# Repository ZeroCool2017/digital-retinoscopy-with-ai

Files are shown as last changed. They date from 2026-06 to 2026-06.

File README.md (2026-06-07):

# Digital Retinoscopy with AI

A self-contained digital retinoscope head that replaces the rubber eyecup on any standard retinoscope. Real-time reflex visualization on a round display. Under $50 in parts.

**Built by an optometrist, for the 1 billion people without access to basic eye exams.**

## What it is

- ESP32-S3 XIAO Sense camera → 240x240 round GC9A01 display
- Real-time retinoscopy reflex — no phone, no laptop, no cloud
- 3D printed housing replaces the rubber eyecup
- 20D 55mm lens for magnification with adjustable sliding focus
- Battery-powered (JST 1.25mm LiPo, 500-1000mAh)
- Total BOM cost: ~$34-50

## Repository contents

```
firmware/
  standalone_demo.ino    — working OV2640 firmware (RGB565, ~15fps)

hardware/
  stl/                   — 2 STL files for printing
    ret-adapter-main-body.stl
    ret-adapter-lens-carriage.stl
  ret-adapter.scad       — parametric OpenSCAD design
  generate_stl.py        — Python script to regenerate STLs

docs/
  eyemote-pitch.md       — general pitch / grant proposal
  eyemote-pitch-lanier.md — pitch for Jaron Lanier / Microsoft Research
  CITATIONS.md           — references and sources
```

## Print settings

| Part | Material | Layer | Supports | Infill |
|---|---|---|---|---|
| Main body | PETG | 0.15-0.2mm | None | 25% |
| Lens carriage | PETG | 0.15mm | None | 25% |

## Assembly

1. Press 20D 55mm lens into lens carriage
2. Insert OV2640 camera module into body pocket, route FPC ribbon through slot
3. Slide lens carriage into front of body — twist to focus
4. Mount XIAO + LiPo battery on the flat back pocket
5. Round display mounts on the back facing you
6. Slide peephole socket over retinoscope tube (replaces rubber eyecup)
7. Twist lens carriage until reflex is sharp on screen

## BOM

| Part | Cost |
|---|---|
| XIAO ESP32S3 Sense | ~$12 |
| GC9A01 round display | ~$8 |
| 20D 55mm lens | ~$6 |
| LiPo battery 500mAh JST1.25 | ~$6 |
| 3D printed parts | ~$2 |
| Misc (ribbon, wire) | ~$2 |
| **Total** | **~$34-50** |

## Next: AI pipeline

Current prototype is standalone camera→display. Next step:
- Raspberry Pi data capture for reflex video recording
- Upload pipeline for AI-based retinopathy screening
- Telemedicine — remote preceptor sees what student sees

## License

Open source — hardware design and firmware.

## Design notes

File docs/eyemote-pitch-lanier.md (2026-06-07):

# Eyemote — Pitch for Jaron Lanier / Microsoft Research

**Subject: A $50 digital retinoscope — hardware is built, need the data pipeline**

---

Jaron,

I'm an optometrist in Oklahoma (Caddo Nation) and a self-taught hardware engineer. I built a digital retinoscope head that replaces the rubber eyecup on any standard retinoscope for $50 in parts.

**What it is:**
ESP32-S3 XIAO Sense camera → round 240x240 display. Real-time. No phone. No laptop. No cloud. The examiner sees the retinoscopy reflex on the display instead of through a peephole. The whole device slides onto the retinoscope the same way the rubber eyecup did.

**What it costs:**
- Parts: $34–$50
- Commercial equivalent (Keeler): $3,000
- That's not a 2x difference. That's 60x.

**Why it matters:**
1 billion people lack access to basic eye exams. Retinoscopy is how every child gets their first glasses — but it's the hardest skill to teach because the preceptor can't see what the student sees. A $50 device that shows the reflex in real-time changes who can learn this skill, where it can be practiced, and how much it costs to deliver.

Microsoft AI for Health already has AI models for diabetic retinopathy screening. Those models need high-quality input. My device can produce that input in any clinic, for $50, connected to a Raspberry Pi.

**What I need from Microsoft Research:**
- Help with the Raspberry Pi data pipeline (recording reflex video, structured data upload)
- A connection to the AI for Health team for clinical validation
- $15k–$30k for 100 field-test units in rural Oklahoma and tribal clinics

**What Microsoft gets:**
- A hardware platform that feeds real retinoscopy data into your AI pipeline
- A direct deployment path into underserved communities (I'm already in them)
- A demonstration that low-cost open-source hardware can match clinical-grade tools

I built the thing. The STLs print in 4 hours. The lens is in hand. The camera works. What I don't have is the software layer that turns a live reflex into a recorded, uploadable, AI-readable dataset.

Do you know anyone at Microsoft who'd want to close that gap with me?

— Dr. Lindsey Marvel, O.D.
  Eyemote Vision, Caddo Nation, Oklahoma

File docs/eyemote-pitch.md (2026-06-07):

# Eyemote: A $50 Digital Retinoscope for Global Eye Care

**Who I am**
Dr. Lindsey Marvel, O.D. — optometrist, Caddo Nation, Oklahoma. Self-taught hardware engineer. I've spent the last year building the hardware I wish existed when I was learning retinoscopy.

**The problem**
Retinoscopy is the single most important skill for determining a patient's prescription — especially in children, nonverbal patients, and anyone who can't sit through a subjective refraction. It's also the hardest skill to teach and learn.

Commercial digital retinoscopes (Keeler, Welch Allyn) cost $3,000–$8,000. They're video recorders bolted onto a $50 light. They don't help you *see* the reflex better — they help you *record* it. A whole generation of optometry students graduates without confidence in retinoscopy because their preceptor can't look through the scope with them.

**The solution**
A self-contained digital retinoscope head that replaces the rubber eyecup. It costs under $50 in parts:

- ESP32-S3 XIAO Sense ($12) — camera + processor + WiFi
- Round 240x240 GC9A01 display ($8)
- 20D 55mm magnifying lens ($6)
- 3D printed housing ($2)
- 500mAh LiPo battery ($6)

Total: ~$34–$50 depending on sourcing.

**How it works**
The camera captures the retinoscopy streak reflex in real-time. The round display shows it to the examiner — no phone, no laptop, no cable, no cloud. The whole device replaces the rubber eyecup on any standard retinoscope. You hold the retinoscope normally, look at the display instead of the peephole, and see the reflex in real-time — exactly the same motion you already use.

**The underserved angle**
Retinoscopy is how every child gets their first glasses prescription. In rural Oklahoma, on tribal lands, in community health centers — there are clinics where a $3,000+ digital retinoscope will never be approved. A $50 device that fits in a pocket doesn't need purchase orders. It doesn't need IT support. It needs a USB-C cable and a 3D printer.

For global eye care: the World Health Organization estimates 1 billion people lack access to basic eye exams. The equipment gap isn't technology — it's cost. A device at this price point changes who gets care and who doesn't.

**Where it goes next**
The current prototype is standalone: camera → display, real-time, no latency. The next step is adding a Raspberry Pi data pipeline for:

- Recording reflex videos for teaching
- Uploading to Microsoft AI for diabetic retinopathy screening
- Telemedicine: a remote preceptor can see exactly what the student sees
- Training AI models on real retinoscopy reflexes (nobody has this dataset)

**What I need**
- $15,000–$30,000 to refine the hardware, run clinical validation, and produce 100 units for field testing
- An engineering partner to help with the Raspberry Pi integration and data pipeline
- Clinical partners in rural and underserved settings to test and validate

**Why now**
Microsoft AI for Health has the AI. Keeler has the $3,000 device. Nobody has connected them to the 200,000 optometrists who just need a $50 tool to do their job better. The hardware is done. The lens is in hand. The STL files print in 4 hours. The only missing piece is the bridge between clinic and cloud.

---

**Contact**
Dr. Lindsey Marvel, O.D.
Eyemote Vision
Caddo Nation, Oklahoma

*"I can't see the reflex" should never be the reason a child goes without glasses.*

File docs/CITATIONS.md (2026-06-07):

# References

## Global eye care burden

1. World Health Organization. *World report on vision*. Geneva: WHO, 2019.
   - 1 billion people worldwide have a vision impairment that could have been prevented or is yet to be addressed.
   - https://www.who.int/publications/i/item/9789241516570

2. Burton MJ, et al. *The Lancet Global Health Commission on Global Eye Health: vision beyond 2020*. Lancet Glob Health. 2021;9(4):e489-e551.
   - https://doi.org/10.1016/S2214-109X(20)30488-5

3. Resnikoff S, et al. *Estimated number of ophthalmologists worldwide*. Int Ophthalmol. 2020;40(7):1579-1591.

## Retinoscopy & refraction

4. American Academy of Ophthalmology. *Basic and Clinical Science Course: Clinical Optics*. 2023-2024.
   - Standard reference for retinoscopy technique and equipment.

5. Hrynchak P, et al. *The accuracy of retinoscopy*. Optom Vis Sci. 2013;90(9):1003-1010.

## Low-cost diagnostic devices

6. Bastawrous A, et al. *Development and validation of a smartphone-based visual acuity test (Peek Acuity) for clinical practice and community-based fieldwork*. JAMA Ophthalmol. 2015;133(8):930-937.
   - Demonstrates smartphone-based eye care tools meeting clinical standards.

7. Hong K, et al. *Smartphone fundus photography: a narrative review*. Ann Transl Med. 2021;9(10):889.

8. Ludwig CA, et al. *3D-printed smartphone ophthalmoscope: a low-cost alternative*. J Glaucoma. 2018;27(7):e122-e124.

## AI in eye care

9. Gulshan V, et al. *Development and validation of a deep learning algorithm for detection of diabetic retinopathy in retinal fundus photographs*. JAMA. 2016;316(22):2402-2410.
   - Landmark paper from Google AI / Verily.

10. Ting DSW, et al. *Artificial intelligence and deep learning in ophthalmology*. Br J Ophthalmol. 2019;103(2):167-175.

11. Rajpurkar P, et al. *AI in health and medicine*. Nat Med. 2022;28(1):31-38.

## Access and equity

12. Sommer A, et al. *Eye care equity and the social determinants of health*. Ophthalmology. 2021;128(7):e86-e92.

13. Seva Foundation. *Annual report: sight restoration in underserved communities*. 2023.
    - https://www.seva.org

## Commercial digital retinoscopes

14. Keeler Instruments. *Keeler Digital Retinoscope*. Product specifications and pricing.

15. Welch Allyn. *SureSight Vision Screener*. Product specifications.

## DIY & open-source ophthalmic devices

16. Open Ophthalmic. *Open-source slit lamp adapters and ophthalmoscope designs*.
    - https://openophthalmic.org

## Microsoft AI for Health

17. Microsoft Corp. *AI for Health program*. 
    - https://www.microsoft.com/en-us/ai/ai-for-health

## Indigenous data sovereignty (Caddo context)

18. Carroll SR, et al. *The CARE Principles for Indigenous Data Governance*. Data Sci J. 2020;19(1):43.
    - Collective Benefit, Authority to Control, Responsibility, Ethics

19. First Nations Information Governance Centre. *The First Nations Principles of OCAP*.
    - Ownership, Control, Access, Possession

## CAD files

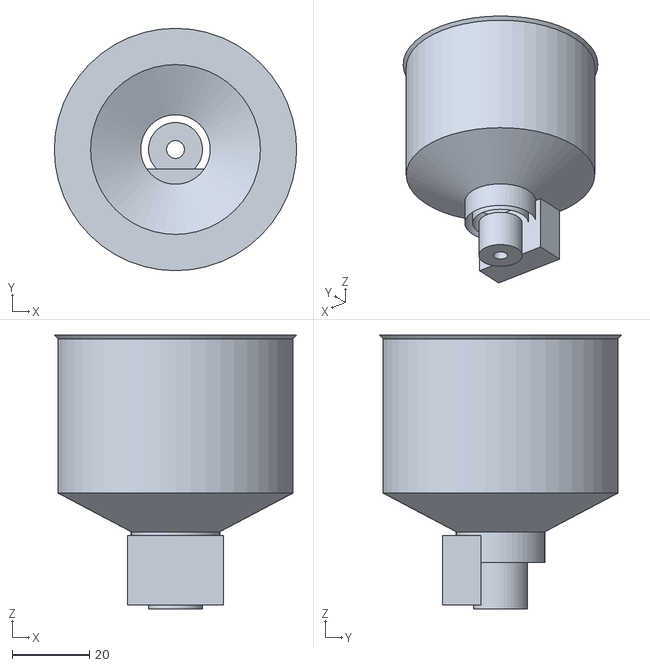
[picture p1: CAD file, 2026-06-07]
hardware/stl/ret-adapter-main-body.stl
62.8 x 62.8 x 71.0

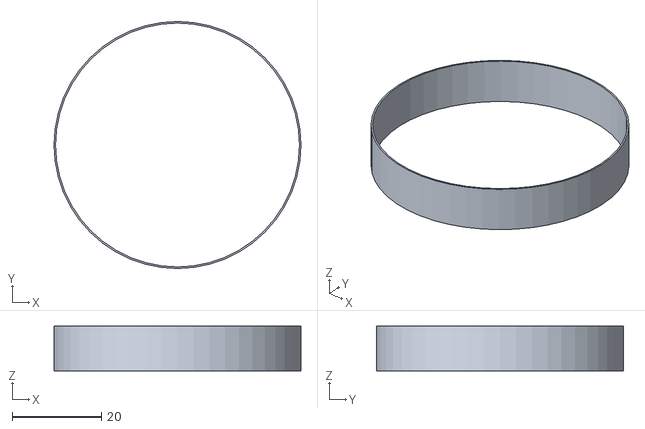
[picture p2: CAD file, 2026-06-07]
hardware/stl/ret-adapter-lens-carriage.stl
55.5 x 55.5 x 10.0

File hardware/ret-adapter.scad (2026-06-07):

/*
 * Eyemote Retinoscope Adapter — parametric OpenSCAD design
 *
 * A self-contained digital retinoscope head that replaces the
 * rubber eyecup on any standard retinoscope.
 *
 * PARTS:
 *   1. main_body()     — the body tube with peephole socket, camera pocket, lens bore
 *   2. focus_ring()    — holds the 20D 55mm lens, slides into lens bore for focus
 *
 * PRINT SETTINGS:
 *   Material: PETG
 *   Layer: 0.15-0.2mm
 *   Supports: NONE (bridges under 5mm)
 *   Infill: 25%
 *   Orient main body with large flat face down
 */

// ═══════════════════════════════════════════════════
//  PARAMETERS
// ═══════════════════════════════════════════════════

// Retinoscope peephole
PEEP_OD = 4.54;         // outer diameter of peephole tube (mm)
SOCKET_DEPTH = 12;      // how deep the socket goes over the tube

// 20D magnifying lens
LENS_DIA   = 55;         // outer diameter of the 20D lens (mm)
LENS_THICK = 5;          // lens edge thickness (mm)
LENS_FOCAL = 50;         // 20D = 50mm focal length (mm)

// Camera module (OV2640 for XIAO ESP32S3 Sense)
CAM_W = 12;              // module width (mm)
CAM_H = 10;              // module height (mm)
CAM_D = 6;               // module depth including lens barrel (mm)

// XIAO ESP32S3 Sense
XIAO_W = 21;
XIAO_H = 17.5;
XIAO_D = 4;

// Round display (GC9A01)
DISP_DIA = 27.5;
DISP_THICK = 4;

// Body geometry
WALL = 2.5;              // wall thickness (mm)
CLEAR = 0.3;             // sliding clearance (mm)

// Derived
SOCKET_OD = 14;          // outer diameter of the peephole socket
BODY_ID = 18;            // inner diameter of the main body section
LENS_BORE_ID = LENS_DIA + 0.8;  // bore for lens (with clearance, mm)
LENS_BORE_OD = LENS_BORE_ID + 2*WALL;  // outer diameter at lens end

// Z-axis convention:
// Z=0 = camera sensor plane
// Negative Z = toward retinoscope (back)
// Positive Z = toward lens (front)

// Body section lengths
BACK_LEN = 12;           // from peephole socket base to camera sensor (mm)
BODY_LEN = 8;            // body section before flare (mm)
FLARE_LEN = 10;          // length of the flare section (mm)
LENS_SEAT_LEN = 8;       // depth of the lens holder section (mm)

// Total body from sensor to tip
TOTAL_FRONT = BODY_LEN + FLARE_LEN + LENS_SEAT_LEN;

// Focus ring
RING_H = LENS_THICK + 3 + 15;  // lens thickness + grip + focus travel
RING_FLANGE_H = 2;              // thickness of the front retaining flange

// ═══════════════════════════════════════════════════
//  MODULE: Main body
// ═══════════════════════════════════════════════════

module main_body() {
    // The body is built as a single piece and then we subtract all the hollow parts.
    $fn = 64;
    
    difference() {
        // ── Solid body ──────────────────────────
        union() {
            // Peephole socket (small tube at back)
            translate([0, 0, -SOCKET_DEPTH])
            cylinder(d = SOCKET_OD, h = SOCKET_DEPTH + 0.5);
            
            // Main body tube (straight section)
            cylinder(d = BODY_ID + 2*WALL, h = BODY_LEN);
            
            // Flare section (cone from body OD to lens bore OD)
            translate([0, 0, BODY_LEN])
            cylinder(
                d1 = BODY_ID + 2*WALL,
                d2 = LENS_BORE_ID + 2*WALL,
                h = FLARE_LEN
            );
            
            // Lens holder section (straight)
            translate([0, 0, BODY_LEN + FLARE_LEN])
            cylinder(d = LENS_BORE_ID + 2*WALL, h = LENS_SEAT_LEN);
            
            // Additional front lip
            translate([0, 0, BODY_LEN + FLARE_LEN + LENS_SEAT_LEN])
            cylinder(d = LENS_BORE_ID + 2*WALL + 2, h = 3);
        }
        
        // ── Subtractions ────────────────────────
        
        // Peephole bore
        translate([0, 0, -SOCKET_DEPTH - 1])
        cylinder(d = PEEP_OD + 0.3, h = SOCKET_DEPTH + 2);
        
        // Main bore (camera section)
        translate([0, 0, -1])
        cylinder(d = BODY_ID, h = BODY_LEN + 2);
        
        // Flare bore
        translate([0, 0, BODY_LEN - 1])
        cylinder(
            d1 = BODY_ID,
            d2 = LENS_BORE_ID,
            h = FLARE_LEN + 2
        );
        
        // Lens bore
        translate([0, 0, BODY_LEN + FLARE_LEN - 1])
        cylinder(d = LENS_BORE_ID, h = LENS_SEAT_LEN + 5);
        
        // Camera module pocket
        // Position: camera module sits ~10mm in front of sensor, on the tube wall
        translate([0, BODY_ID/2, BODY_LEN/2])
        cube([CAM_W + 1, CAM_D + 2, CAM_H + 1], center = true);
        
        // FPC ribbon slot
        translate([CAM_W/2 + 2, 0, BODY_LEN/2])
        cube([3, 20, CAM_H/2 + 1], center = true);
        
        // XIAO mount cutout (flat area on the side)
        translate([0, -(BODY_ID + 2*WALL)/2 - 4, -3])
        cube([XIAO_W + 4, 8, XIAO_D + 10], center = true);
        
        // Display hole (viewing cutout through the body wall)
        translate([0, -(BODY_ID + 2*WALL)/2 - 1, 4])
        cylinder(d = 18, h = 8, $fn = 48);
        
        // USB access slot
        translate([0, -(BODY_ID + 2*WALL)/2 - 1, -XIAO_D/2 - 2])
        cube([9, 6, 5], center = true);
        
        // Weight relief holes
        for (a = [0 : 60 : 300]) {
            rotate([0, 0, a])
            translate([(BODY_ID + 2*WALL)/2 + 1, 0, BODY_LEN/2])
            rotate([90, 0, 0])
            cylinder(d = 3, h = (BODY_ID + 2*WALL) + 2);
        }
    }
}

// ═══════════════════════════════════════════════════
//  MODULE: Focus ring (holds the 20D lens)
// ═══════════════════════════════════════════════════

module focus_ring() {
    $fn = 64;
    
    ring_od = LENS_BORE_ID - CLEAR;        // slides inside the lens bore
    ring_bore = LENS_DIA - 0.2;             // press-fit for the lens
    
    difference() {
        // Outer ring
        cylinder(d = ring_od, h = RING_H);
        
        // Lens bore
        translate([0, 0, -1])
        cylinder(d = ring_bore, h = RING_H - LENS_THICK + 1);
        
        // Lens seat ledge (smaller ID so the lens rests on it)
        translate([0, 0, RING_H - LENS_THICK - 1.5])
        cylinder(d = LENS_DIA - 2, h = LENS_THICK + 2);
        
        // Front access (lets light through to the lens)
        translate([0, 0, -1])
        cylinder(d = 45, h = 2);  // 45mm clear aperture
        
        // Finger grip grooves
        for (i = [0 : 11]) {
            rotate([0, 0, i * 30])
            translate([ring_od/2 + 1, 0, RING_H/2])
            rotate([90, 0, 0])
            cylinder(d = 3.5, h = ring_od/2 + 2);
        }
        
        // Lightening holes
        for (i = [0 : 5]) {
            rotate([0, 0, i * 60 + 15])
            translate([(ring_od - 4)/2, 0, RING_H/2])
            rotate([90, 0, 0])
            cylinder(d = 5, h = ring_od);
        }
    }
}

// ═══════════════════════════════════════════════════
//  RENDER
// ═══════════════════════════════════════════════════

// Uncomment the part you want to export:

// main_body();
// translate([0, 0, TOTAL_FRONT + 10]) focus_ring();

// Assembly view:
// color("gray", 0.5) main_body();
// translate([0, 0, 55]) color("orange") focus_ring();

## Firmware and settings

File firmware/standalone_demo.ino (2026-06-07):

// Eyemote Standalone Demo v2
// XIAO ESP32S3 Sense OV2640 camera → Seeed round display
// RGB565 direct — clean, fast, works
//
// Compile: arduino-cli compile --fqbn esp32:esp32:XIAO_ESP32S3:PSRAM=opi ~/eyemote-xiao-test/standalone_demo
// Upload:  arduino-cli upload -p /dev/ttyACM0 --fqbn esp32:esp32:XIAO_ESP32S3:PSRAM=opi ~/eyemote-xiao-test/standalone_demo

#include "esp_camera.h"
#include <TFT_eSPI.h>

#define PWDN_GPIO_NUM     -1
#define RESET_GPIO_NUM    -1
#define XCLK_GPIO_NUM     10
#define SIOD_GPIO_NUM     40
#define SIOC_GPIO_NUM     39

#define Y9_GPIO_NUM       48
#define Y8_GPIO_NUM       11
#define Y7_GPIO_NUM       12
#define Y6_GPIO_NUM       14
#define Y5_GPIO_NUM       16
#define Y4_GPIO_NUM       18
#define Y3_GPIO_NUM       17
#define Y2_GPIO_NUM       15
#define VSYNC_GPIO_NUM    38
#define HREF_GPIO_NUM     47
#define PCLK_GPIO_NUM     13

TFT_eSPI tft = TFT_eSPI();

#define CAM_W     320
#define CAM_H     240
#define DISP_W    240
#define DISP_H    240

static uint16_t *disp_buf = NULL;

bool initCamera() {
  camera_config_t config;
  config.ledc_channel = LEDC_CHANNEL_0;
  config.ledc_timer   = LEDC_TIMER_0;

  config.pin_d0       = Y2_GPIO_NUM;
  config.pin_d1       = Y3_GPIO_NUM;
  config.pin_d2       = Y4_GPIO_NUM;
  config.pin_d3       = Y5_GPIO_NUM;
  config.pin_d4       = Y6_GPIO_NUM;
  config.pin_d5       = Y7_GPIO_NUM;
  config.pin_d6       = Y8_GPIO_NUM;
  config.pin_d7       = Y9_GPIO_NUM;
  config.pin_xclk     = XCLK_GPIO_NUM;
  config.pin_pclk     = PCLK_GPIO_NUM;
  config.pin_vsync    = VSYNC_GPIO_NUM;
  config.pin_href     = HREF_GPIO_NUM;
  config.pin_sccb_sda = SIOD_GPIO_NUM;
  config.pin_sccb_scl = SIOC_GPIO_NUM;
  config.pin_pwdn     = PWDN_GPIO_NUM;
  config.pin_reset    = RESET_GPIO_NUM;

  config.xclk_freq_hz = 20000000;
  config.pixel_format = PIXFORMAT_RGB565;
  config.frame_size   = FRAMESIZE_QVGA;
  config.fb_count     = 2;
  config.grab_mode    = CAMERA_GRAB_LATEST;
  config.fb_location  = CAMERA_FB_IN_PSRAM;

  esp_err_t err = esp_camera_init(&config);
  if (err != ESP_OK) {
    Serial.printf("CAMERA INIT FAILED: 0x%x\n", err);
    return false;
  }

  sensor_t *s = esp_camera_sensor_get();
  if (s) {
    s->set_brightness(s, 0);
    s->set_contrast(s, 1);
    s->set_saturation(s, 0);
    s->set_sharpness(s, 1);
    s->set_gain_ctrl(s, 1);
    s->set_exposure_ctrl(s, 1);
    s->set_whitebal(s, 1);
    s->set_hmirror(s, 0);
    s->set_vflip(s, 0);
  }

  return true;
}

void setup() {
  Serial.begin(115200);
  delay(2000);

  Serial.println("\n=== Eyemote Standalone Demo ===\n");

  if (!psramFound()) {
    Serial.println("PSRAM: NOT FOUND");
    return;
  }
  Serial.println("PSRAM: OK (8MB)");

  tft.begin();
  tft.setRotation(3);
  tft.fillScreen(TFT_BLACK);
  tft.setTextColor(TFT_WHITE, TFT_BLACK);
  tft.setTextSize(1);

  pinMode(TFT_BL, OUTPUT);
  digitalWrite(TFT_BL, HIGH);

  tft.setCursor(10, 80);
  tft.println("Eyemote");
  tft.setCursor(10, 100);
  tft.println("Standalone");
  tft.setCursor(10, 120);
  tft.println("v2");

  disp_buf = (uint16_t *)ps_malloc(DISP_W * DISP_H * sizeof(uint16_t));
  if (!disp_buf) {
    Serial.println("PSRAM allocation failed!");
    tft.setCursor(10, 140);
    tft.println("PSRAM FAILED");
    return;
  }
  Serial.println("Display buffer allocated");

  if (!initCamera()) {
    Serial.println("Camera init failed");
    tft.setCursor(10, 140);
    tft.println("Camera FAILED");
    return;
  }
  Serial.println("Camera OK");

  tft.fillScreen(TFT_BLACK);
  tft.setCursor(30, 100);
  tft.println("Eyemote");
  tft.setCursor(20, 120);
  tft.println("Ready");
  delay(1000);

  Serial.println("=== READY ===\n");
}

void loop() {
  camera_fb_t *fb = esp_camera_fb_get();
  if (!fb) {
    delay(10);
    return;
  }

  // RGB565 direct: crop 320x240 to center 240x240
  const int x_offset = (CAM_W - DISP_W) / 2;
  uint16_t *src = (uint16_t *)fb->buf;
  for (int y = 0; y < DISP_H; y++) {
    memcpy(disp_buf + y * DISP_W, src + y * CAM_W + x_offset, DISP_W * 2);
  }

  tft.pushImage(0, 0, DISP_W, DISP_H, disp_buf);

  // Subtle crosshair
  tft.drawLine(120-30, 120, 120+30, 120, 0xAD55);
  tft.drawLine(120, 120-30, 120, 120+30, 0xAD55);

  esp_camera_fb_return(fb);
}

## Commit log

2026-06-07 Initial commit: working firmware, STLs, OpenSCAD design, pitch docs
    [ret-adapter-centering-ring.stl, ret-adapter-lens-carriage.stl, ret-adapter-main-body.stl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]
2026-06-07 Fix CAD: correct focal distance (50mm), peephole socket, focus ring, flare, XIAO mount
    [ret-adapter-lens-carriage.stl, ret-adapter-main-body.stl, ret-adapter.scad]
2026-06-07 Clean up: remove centering ring STL, fix README to match current design
    [ret-adapter-centering-ring.stl]
